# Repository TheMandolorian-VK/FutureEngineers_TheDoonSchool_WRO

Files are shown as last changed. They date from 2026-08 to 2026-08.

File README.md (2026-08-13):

<div align="center">

# The Doon School: WRO Future Engineers 2026

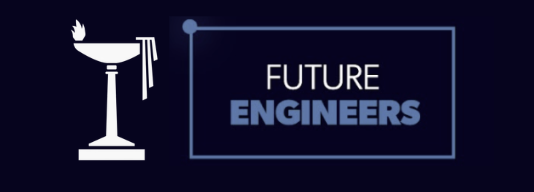
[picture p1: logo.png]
The Doon School: WRO Future Engineers 2026


### Engineering the autonomous vehicle for the World Robot Olympiad Future Engineers category

[Explore the project](#explore-the-project) · [System architecture](#system-architecture) · [Team](#team) · [Roadmap](#development-roadmap)

</div>

---

## Table of Contents

- [Overview](#overview)
- [Team](#team)
- [System Architecture](#system-architecture)
- [Mechanical Design](#mechanical-design)
- [Electronics and Power](#electronics-and-power)
- [Software and Obstacle Strategy](#software-and-obstacle-strategy)
- [Testing, Iteration and Evidence](#testing-iteration-and-evidence)
- [Visuals](#visuals)
- [Build and Upload](#build-and-upload)
- [Repository Use and Attribution](#repository-use-and-attribution)
- [Explore the Project](#explore-the-project)
- [Robot Visualisations](#robot-visualisations)
- [Documentation Standard](#documentation-standard)
- [Development Roadmap](#development-roadmap)
- [Repository History](#repository-history)
- [License](#license)

---

## Overview

This repository documents our work for **The Doon School Future Engineers** team competing at **WRO 2026 (GMR Arena, Hyderabad, 26–28 August 2026)**.

It captures the team's submitted vehicle configuration, software architecture, documentation structure, and engineering process. The vehicle is a 4-wheel autonomous car built to the WRO 2026 Future Engineers rules:

- **One driving axle + one steering actuator** per WRO rules.
- **Envelope:** ≤ 300 × 200 × 300 mm; **mass:** ≤ 1.5 kg.
- **No wireless** control during the run.

This documents our current vehicle design. Specifications, code, renders, and test results are in separate sections.

---

## Team

| Member | Focus |
| --- | --- |
| Dhrubo Mishra | Mechanical design |
| Vivaan Kumbhat | Software development |
| Yug Jain | Electronics, systems, and repository integration |
| Mr. Ashutosh Tripathi | Head mentor |

**School:** The Doon School, Dehradun, India
**Category:** WRO 2026: Future Engineers

---

## System Architecture

The vehicle separates **high-level perception and decision-making** (Raspberry Pi 4B) from **low-level actuator control** (ESP32). The Pi interprets the camera, decides steering/speed targets, and sends bounded commands over USB serial; the ESP32 drives the servo and motor and holds the safety state machine.

```text
Pi Camera Module 3 Wide
        │
Raspberry Pi 4B  ──(USB serial, 115200 baud)──►  ESP32
        │                                            │
   perception +                                   MG996R servo
     decision                                     (Ackermann)
                                                  TB6612FNG → N20 (rear axle)
```

| Layer | Input | Responsibility | Output | Module |
| --- | --- | --- | --- | --- |
| Perception | Camera frames | Detect colour cues / geometry | Feature observations | Pi camera + `wromain.py` |
| Decision | Observations + vehicle state | Route, avoid, recover, stop | Steering + speed targets | `wromain.py` |
| Control | Steering + speed targets | Constrain & actuate | Servo / PWM signals | `obstacleChallenge.ino` |
| Vehicle | Actuator signals | Steering + propulsion | Physical motion | Chassis + drivetrain |

> [!NOTE]
> This architecture is the submitted engineering reference. Test records and implementation evidence are kept separately from the configuration description.

### Vehicle specification (submitted configuration)

| Item | Specification |
| --- | --- |
| High-level compute | Raspberry Pi 4B |
| Low-level controller | ESP32 DevKit |
| Camera | Raspberry Pi Camera Module 3 **Wide** |
| Drive | **Rear-wheel drive**, 1 × N20 6 V 600 RPM on the rear axle |
| Steering | Front **MG996R** servo + **Ackermann linkage (LEGO beams/pins)**, 40° outer lock |
| Distance sensing | **VL53L0X** ToF (primary) + **HC-SR04** ultrasonic (redundant) |
| Orientation | **MPU6050** 6-axis IMU (DFRobot Fermion) |
| Motor driver | **TB6612FNG** (1 A/channel) |
| Chassis | 3 mm laser-cut plywood (LightBurn), brass standoff offsets, two decks |
| Battery | **11 V 3S LiPo** → motor/servo rail ~6 V (within N20 6 V and MG996R 4.8–7.2 V ratings); logic rail 5 V |
| Envelope / mass | ≤ 300 × 200 × 300 mm, ≤ 1.5 kg |

The rear N20 and its wheels are deliberately **smaller than the front wheels**, lowering the drive mass and giving the chassis a slight rearward tilt for corner stability.

---

## Mechanical Design

Full detail: [`design/README.md`](design/README.md).

Key points of the submitted configuration:

- **Front Ackermann steering** driven by an MG996R servo. The steering arms, knuckles and tie-rod geometry are built from **LEGO beams and pins** on a front sub-frame, so the Ackermann trapezoid can be re-jigged in 8 mm steps during tuning without re-cutting the chassis. Outer lock was iterated **31° → 40°** to clear the 600 mm corridor 90° corners (see journal Entry 04).
- **Fully rear-wheel drive** with one N20 6 V 600 RPM motor on the rear axle: Rule 11.13 compliant (one driving axle, no independent side motors). Rear wheels are smaller than the front, producing the rearward tilt described above.
- **Two-deck 3 mm plywood chassis**, laser-cut in **LightBurn**. Upper deck carries the Raspberry Pi 4B + Camera Module 3 Wide; lower deck carries the 11 V 3S LiPo pack, ESP32 and TB6612FNG. The decks are spaced by **brass standoff offsets**, with LEGO used as adjustable mounting rails.
- **Chassis:** 3 mm plywood, laser-cut in LightBurn. The DXF export [`wooden_plate.dxf`](design/wooden_plate.dxf) is committed (currently a placeholder rectangle; see [cut file notes](design/dxf_notes.md)). The full deck patterns and `.lbrn` LightBurn project are pending.
- **Mechanical BOM:** [`design/bom_mechanical.md`](design/bom_mechanical.md) lists every chassis and drivetrain part with status; the electronics parts list is in [`electronics/README.md`](electronics/README.md) (Bill of materials section).

---

## Electronics and Power

Full detail: [`electronics/README.md`](electronics/README.md) · Wiring: [`hardware/wiring-guide/README.md`](hardware/wiring-guide/README.md).

- **Two-rail power from one 11 V 3S LiPo pack:** the motor/servo rail is buck-regulated to ~6 V (within the N20 6 V and MG996R 4.8–7.2 V ratings) for the N20 + MG996R; the logic rail is buck-regulated to 5 V for the Pi 4B, ESP32, HC-SR04, VL53L0X and MPU6050.
- **Star grounding:** all logic grounds meet at one point; motor/servo currents return separately, keeping servo/motor noise out of the logic reference.
- **Protection:** both rails fused. The ESP32 enters `MODE_FAULT` (motor stop + centred steering) on serial timeout (>350 ms) or an invalid command; a logic-rail brownout resets the ESP32 into `MODE_STOP`, which is also motor-off and steering-centred.
- **Pin assignments** for the ESP32 (MG996R → GPIO 13; TB6612FNG PWMA/AIN1/AIN2/STBY → GPIO 25/26/27/32; status LEDs → GPIO 2/4) and the Pi↔ESP32 USB-serial link (115200 baud; messages `CMD,<steer>,<pwm>,<mode>` with `<mode>` ∈ {`DRIVE`, `PARK`, `FINISH`, `STOP`}, plus bare `STOP` and `PING`) are documented in the wiring guide.

> [!NOTE]
> The vehicle is in the development and integration phase; measured rail currents and calibrated values will be added to the testing records as subsystems are verified.

---

## Software and Obstacle Strategy

Full detail: [`strategy/README.md`](strategy/README.md) · Pi code: [`software/raspberry_pi/wromain.py`](software/raspberry_pi/wromain.py) · ESP32 code: [`software/esp32/obstacleChallenge.ino`](software/esp32/obstacleChallenge.ino).

Two-layer software:

- **Raspberry Pi (`wromain.py`):** camera frames → 3×3 colour grid → per-cell HSV masks (red, green, purple (the WRO magenta parking blocks), orange and blue; black is the neutral background cell) → contour detection → target selection → lateral-error **PD steering** → dynamic drive speed. PD (not full PID) is used deliberately: no sustained steady-state error needs the integral term, and D-only damping prevents corner oscillation.
- **ESP32 (`obstacleChallenge.ino`):** executes bounded commands through a safety state machine with internal states `MODE_DRIVE`, `MODE_PARK`, `MODE_STOP`, `MODE_FINISH`, `MODE_FAULT` (the Pi sends only the wire tokens `DRIVE`, `PARK`, `FINISH`, `STOP` and `PING`; invalid input drives `MODE_FAULT`). Fault is entered on serial timeout or invalid command: the vehicle always fails safe.

**Obstacle Challenge flow (implemented in code: vision grid + PD steering + watchdog; remaining stages are designed and tracked as planned work):** lane-follow by centring on the corridor (PD on vision offset; wall check is pending the VL53L0X integration) → red pillar pass right / green pillar pass left (colour from the camera grid, +12° bias; ToF clearance check pending) → after 3 laps the Pi sends `PARK`. **Planned but not yet in code:** the start-zone lap detector, the parking manoeuvre, and the IMU heading alignment / ToF depth stop for the magenta (purple) parking blocks. **Open Challenge:** corner handling via the PD controller today; wall-geometry corner detection and orange/blue section-line lap counting are planned.

Edge cases handled in code: lost line (re-acquire by sweep), serial dropout (watchdog fault stop), pillar too close (emergency bias). Planned: parking overshoot recovery with small IMU-controlled steps once the IMU is integrated.

> [!NOTE]
> Build status: the vehicle is in the development and integration phase. Code implements perception (colour grid), PD steering, dynamic speed, and the ESP32 safety state machine; the IMU, VL53L0X ToF, start-zone detector and parking manoeuvre are pending integration (placeholder interfaces in `wromain.py`). Measured results land in [`docs/testing/`](docs/testing/README.md) and [`evidence/`](evidence/README.md) as tests are run.

---

## Testing, Iteration and Evidence

Full detail: [`docs/testing/README.md`](docs/testing/README.md) · Journal: [`docs/engineering_journal/README.md`](docs/engineering_journal/README.md) · Evidence: [`evidence/README.md`](evidence/README.md).

Configuration is kept separate from evidence. A design choice is explained in the architecture/strategy material; an observed conclusion is recorded in the corresponding test record. Each test record lists date, objective, vehicle/software version, setup, procedure, raw observations, result, limitations and next action. Unsuccessful tests are retained as part of the real iteration process.

| Evidence type | Location | Required label |
| --- | --- | --- |
| Design decision | [Engineering journal](docs/engineering_journal/README.md) | Date, author, options, rationale |
| Proposed diagram | [Diagrams / wiring guide](hardware/wiring-guide/README.md) | Proposed + version |
| Physical / software test | [Testing](docs/testing/README.md) | Date, setup, method, observation |
| Test visual | [Test images](images/testing/README.md) | Date and conditions |
| Vehicle view | [Robot images](images/robot/README.md) | Render or dated photograph |
| Run video | [Videos](videos/README.md) | Date, challenge, setup, outcome |

---

## Visuals

The repository keeps team, vehicle, testing and competition visuals in separate folders so context stays clear. Vehicle views in [`images/robot/`](images/robot/README.md) are concept renders of the submitted configuration: design-reference views, not photographs. Competition-day videos are recorded on the day of the event and archived in [`videos/README.md`](videos/README.md).

---

## Build and Upload

The submitted configuration documents the build-and-upload procedure: OS setup, library versions, camera configuration, Pi build command, ESP32 board/environment selection, required libraries (`ESP32Servo`, OpenCV), upload method, communication setup and a safe power-on sequence. Measured verification is maintained in the testing record rather than implied by the instructions.

- Pi: `software/raspberry_pi/wromain.py` (OpenCV + camera input).
- ESP32: `software/esp32/obstacleChallenge.ino` (uses `ESP32Servo`).

Exact dependencies and compile/upload commands belong in the respective software folders, linked to the journal records.

---

## Repository Use and Attribution

This repository contains our own work. We do not copy other teams' designs or code. Git history records our progress.

The documentation is organised against the five WRO 2026 Future Engineers criteria (Mobility & Mechanical Design, Power & Sensor Architecture, Software Architecture & Obstacle Strategy, Systems Thinking & Engineering Decisions, Reproducibility & GitHub Quality). The mapping from each criterion to the relevant files is maintained in [`docs/README.md`](docs/README.md).

---
## Explore the Project

| Area | Contents | Status |
| --- | --- | --- |
| [`design/`](design/) | Vehicle layout, mechanical decisions, LightBurn/DXF, mechanical BOM | Configuration |
| [`electronics/`](electronics/) | Components, power plan, wiring, pin assignments | System reference |
| [`strategy/`](strategy/) | Open / Obstacle Challenge logic and flow | Decision architecture |
| [`software/`](software/) | Raspberry Pi (`wromain.py`) and ESP32 (`obstacleChallenge.ino`) source | Control software |
| [`docs/`](docs/) | Engineering journal, diagrams, testing records | Engineering record |
| [`images/`](images/) | Team, robot (renders), testing, competition visuals | Visual reference |
| [`videos/`](videos/) | Dated run and presentation videos (competition day) | Run records |
| [`evidence/`](evidence/) | Dated reviews, calibration and test summaries | Evidence archive |

---

## Robot Visualisations

Visuals in [`images/robot/`](images/robot/) are concept renders of the submitted vehicle configuration: design-reference views, not photographs.

---

## Documentation Standard

We keep design docs, code, and test results separate.

- Each test record has date, setup, method, observations and next action.
- Renders are not photographs of the real vehicle.
- We keep unsuccessful attempts as part of the learning process.

---

## Development Roadmap

| Phase | Focus | Evidence added when complete |
| --- | --- | --- |
| `01` | Define architecture and component choices | Dated design decision |
| `02` | Assemble and document the first prototype | Labelled photographs and wiring record |
| `03` | Implement perception, control and communication | Source code and software test record |
| `04` | Test subsystems | Measured, dated test results |
| `05` | Integrate the vehicle | Complete challenge evidence |

---

## Repository History

This repository uses GitHub to track our engineering progress. Updates are committed as the team's work evolves.

---

## License

Published for educational use as part of WRO Future Engineers. Team materials may be updated during development.

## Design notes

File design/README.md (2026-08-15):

<div align="center">

# Vehicle Design

**Mechanical design of the WRO 2026 Future Engineers vehicle.**

[← Project home](../README.md) · [Electronics](../electronics/README.md) · [Engineering journal](../docs/engineering_journal/README.md)

</div>

---

## Documentation index

- [Rule compliance checklist](rules_checklist.md) - WRO 2026 requirements mapped to the design
- [Ackermann geometry](ackermann_geometry.md) - steering geometry, iterations and cornering analysis
- [Mass budget](mass_budget.md) - component mass estimates and margins
- [Assembly guide](assembly_guide.md) - step-by-step build sequence
- [Mechanical BOM](bom_mechanical.md) - chassis and drivetrain parts
- [Cut file notes](dxf_notes.md) - what wooden_plate.dxf contains today
- [Design decision log](design_decisions.md) - decisions and rejected alternatives
- [Laser cutter setup](laser_cutter_setup.md) - school laser workflow and kerf
- [Camera mount design](camera_mount.md) - camera placement and mount
- [Steering tuning plan](steering_tuning_plan.md) - on-mat steering verification

---

## 1. Design philosophy

Three constraints drive every mechanical choice:

1. **Rule compliance:** WRO 2026 requires a 4-wheel vehicle with **one driving axle and one steering actuator** (Rules 11.3, 11.5, 11.13). Differential drive and one-motor-per-side are disqualified.
2. **Envelope & mass:** ≤ 300×200×300 mm and ≤ 1.5 kg (Rules 11.1–11.2).
3. **Reproducibility:** everything must be rebuildable from files in this repository (LightBurn/DXF, STL, BOM).

The vehicle uses **front Ackermann steering with a servo** and **fully rear-wheel drive with one N20 motor**, on a **laser-cut 3 mm plywood double-stack chassis**. The rear N20 and its wheels are deliberately smaller than the front wheels, which lowers the drive/steering mass and gives the chassis a slight rearward (backward) tilt for stability through the 90° corners.

> [!NOTE]
> The design uses one driving axle (rear) and one steering actuator (front servo). Physical verification that both rear wheels receive torque is pending.

---

## 2. Design targets

The values below are **design targets** captured from the CAD layout and the current prototype. They are targets, not verified measurements: physical verification (envelope gauge, scale, and track/wheelbase callipers) is pending and will be logged in the engineering journal.

| Parameter | Target | Notes |
| --- | --- | --- |
| Envelope (L×W×H) | ≤ 300×200×300 mm | Hard rule limit (11.1–11.2); layout keeps margin |
| Wheelbase | ~150 mm | Distance between front and rear axle centres |
| Track (front / rear) | ~140 mm | Wheel centre spacing, kept equal for Ackermann |
| Deck spacing | ~35 mm | Vertical gap between upper and lower plywood decks |
| Ground clearance | ~12 mm | Chassis underside to mat; set by deck height and wheel size |
| Total mass | ≤ 1.5 kg | Target; see mass budget below |

### Mass budget

Component masses to be measured once the vehicle is assembled (see [mass budget](mass_budget.md)). The rule limit is 1.5 kg.

---

## 3. Steering: Ackermann geometry

**Why Ackermann:** at a corner, the inner front wheel must turn tighter than the outer front wheel, so all four wheels roll about a single instant centre. Without this (parallel steering), tyres scrub sideways, grip drops, and the car is unstable at speed: exactly what kills run consistency.

### Steering mechanism

- **Actuator:** TowerPro MG996R digital servo (high torque, metal gears).
- **Linkage:** servo horn → tie rod → steering knuckles (3D-printed), forming the Ackermann trapezoid. The steering arms, knuckles and tie-rod geometry are built from **LEGO beams and pins** on a front sub-frame, giving an adjustable, repeatable Ackermann trapezoid that can be re-jigged in 8 mm steps during tuning without re-cutting the chassis.
- **Geometry parameters (current):**
  - Maximum outer-wheel steer angle: **31°** (prototype 1)
  - Maximum outer-wheel steer angle: **40°** (prototype 2, current)
  - Inner/outer angle difference follows the Ackermann condition
    `cot(δ_o) − cot(δ_i) = track / wheelbase`.

### 31° → 40° iteration

| Parameter | Prototype 1 | Prototype 2 | Decision |
| --- | --- | --- | --- |
| Max steer angle | 31° | 40° | 40° selected |
| Turning radius (1000 mm corridor) | OK | Tighter | 40° |
| 600 mm corridor 90° corner clearance | clipped wall line (~0 mm) | ~80 mm each side | 40° |
| Servo transition harshness | Soft | Slightly harsher | Softened in PD control near lock |

The 40° lock lets the car execute the sharp 90° corners of the 600 mm corridor configuration while the PD controller softens gain near lock to avoid jerky transitions.

---

## 4. Chassis: laser-cut 3 mm plywood (LightBurn)

- **Material:** 3 mm plywood: lighter than acrylic at equal stiffness, damps motor vibration, doesn't crack at screw points, cuts cleanly and fast.
- **Tool:** school laser cutter, designed in **LightBurn**. The DXF export is committed as [`wooden_plate.dxf`](wooden_plate.dxf); see [cut file notes](dxf_notes.md)). The editable `.lbrn` LightBurn project and full deck patterns are pending.
- **Edge treatment:** two thin coats of clear varnish seal the cut edges against moisture and warp.

### Material tradeoff

| Material | Stiffness/weight | Cutting/fab | Durability | Verdict |
| --- | --- | --- | --- | --- |
| 3 mm plywood | Good stiffness per gram | Laser-cuts fast and clean | Damps vibration, resists screw cracking | **Selected** |
| Acrylic | Similar weight, more brittle | Laser-cuts well | Cracks at screw points under load | Rejected |
| 3D-printed (PLA/PETG) | Lower stiffness at low mass | Slow, layer-dependent | Flexible, warps near motors | Rejected for structure |
| Aluminium | Highest stiffness | Needs CNC/mill, not the school laser | Very durable, but heavier | Rejected (mass + tooling) |

The chassis prioritises low mass, fast iteration, and vibration damping on the school laser cutter. Plywood wins on all three against the alternatives above.

### LightBurn cut workflow (reproducibility)

The chassis is drawn in **LightBurn** and cut on the school laser cutter from 3 mm plywood. Reproducibility (Criterion 5) depends on the cut files carrying everything needed to re-cut the chassis identically:

- **Layers:** the lower deck carries the drivetrain/electronics cut-outs; the upper deck carries the Pi + camera-mount cut-outs and the brass-standoff holes.
- **Parameters recorded per file:** material (3 mm plywood), kerf compensation, and the cutter's power/speed setting for that material.
- **Files:** the DXF export [`wooden_plate.dxf`](wooden_plate.dxf) is committed. The editable `.lbrn` master and full deck patterns are pending.

### Double-stack layout: space utilisation

The 300×200 mm footprint is used vertically to fit the full system:

| Deck | Contents | Why |
| --- | --- | --- |
|  **Lower deck** | 11 V 3S LiPo pack, ESP32, TB6612FNG motor driver | Battery low for CG; short motor/servo wiring; servo + drive currents kept off the logic reference |
|  **Upper deck** | Raspberry Pi 4B, Camera Module 3 Wide | Camera horizon height ~120 mm; Pi clear of motor noise sources |

The two decks are separated and supported by **brass standoff offsets**, giving a rigid, ventilated sandwich that uses the height envelope efficiently.

### Wood + LEGO + brass offsets mounting system

Instead of drilling new holes for every iteration, we fuse three systems:

- **Wood (plywood decks):** primary structure, laser-cut precisely.
- **LEGO beams and pins:** universal mounting rails with a precise 8 mm hole grid: sensors, drivers and brackets can be moved in 8 mm steps without re-cutting the chassis. Quick, repeatable repositioning during testing.
- **Brass standoffs / offsets:** set deck spacing and create rigid mounting pillars; brass threads are far more durable than wood screws when parts are repeatedly removed.

This hybrid makes the mechanical design **iterative by construction**: a camera or sensor that needs a different position is moved in minutes, and the change is photographed for the engineering journal.

---

## 5. Why this layout satisfies the rules

- **One driving axle:** a single N20 motor on the rear axle. Both rear wheels driven through one mechanically coupled axle.
- **One steering actuator:** a single MG996R servo on the front Ackermann linkage.
- **No wireless:** all control and power on board.
- **Envelope and mass:** designed to stay within 300x200x300 mm and 1.5 kg (physical verification pending).

---

## 6. Drive: rear axle, single N20 motor

- **Motor:** N20 6 V 600 RPM micro metal gear motor (spare unit carried).
- **Transmission:** motor drives the rear axle through the gearbox.
- **Wheel:** front wheels ~40 mm diameter, high-traction rubber; **rear wheels are smaller (~30 mm design estimate)**, matched to the smaller rear N20. The rear bias lightens the drive end and produces the slight rearward chassis tilt described in §1; the axle is mechanically coupled (Rule 11.13 compliant: one driving axle, no independent side motors).

### Speed / torque reasoning

- **Top speed (driven wheel):** the driven rear wheels are the smaller ones (~30 mm design estimate), not the ~40 mm front wheels. Circumference ≈ π × 30 mm ≈ 94.2 mm. At the N20 free-run speed of 600 RPM (10 rev/s), the **theoretical no-load speed (design estimate)** is ≈ 94.2 mm × 10 ≈ 0.94 m/s. Real cruise speed is lower because of load, tyre slip, and the PD speed controller leaving margin for corners and parking. We plan to cruise near 0.55 m/s for consistency, well inside the 3-minute round.
- **Torque:** rolling resistance force for the vehicle mass is to be measured on the mat. The N20 stall torque is datasheet-typical and to be bench-confirmed. The design is expected to be speed-limited, not torque-limited: correct for a flat, low-friction mat.

---

## 7. Component placement

| Component | Location | Justification |
| --- | --- | --- |
|  Camera Module 3 Wide | Upper deck, forward | Sees pillars 0.5–1.5 m ahead; reaction distance at cruise speed |
|  VL53L0X ToF | Front centre | Pillar + parking-gap distance, mm-accurate, colour-independent |
|  HC-SR04 ultrasonic | Front corner | Redundant wall proximity (independent bus from I²C sensors) |
|  MPU6050 IMU | Centre of mass | Minimal lever-arm coupling into gyro; heading for turns/parking |
|  Raspberry Pi 4B | Upper deck | Vision processing, high-level decisions |
|  ESP32 | Lower deck | Real-time motor/servo control, safety state machine |
|  MG996R servo | Front axle, centre | Drives Ackermann linkage; shortest linkage run |
|  11 V 3S LiPo battery | Lower deck, rear | Low CG; counterbalances steering assembly; sole energy source for the motor/servo rail |

---

## 8. Current development status

The mechanical design is through its second iteration (31°→40° steering, double-stack chassis assembled). Integration and tuning are ongoing at the school lab; every change is logged in the [engineering journal](../docs/engineering_journal/README.md). The DXF export [`wooden_plate.dxf`](wooden_plate.dxf) is committed; the `.lbrn` master and full deck patterns are pending.

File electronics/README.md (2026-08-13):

<div align="center">

# Electronics

**Pin assignments and basic power-distribution reference for the WRO Future Engineers vehicle.**

[← Project home](../README.md) · [Hardware](../hardware/README.md) · [Wiring Guide](../hardware/wiring-guide/README.md) · [Diagrams](../docs/diagrams/README.md)

</div>

---

## Pinout

### ESP32

| Component | Function | ESP32 Pin |
| --- | --- | ---: |
| MG996R | Steering signal | GPIO 13 |
| TB6612FNG | PWMA | GPIO 25 |
| TB6612FNG | AIN1 | GPIO 26 |
| TB6612FNG | AIN2 | GPIO 27 |
| TB6612FNG | STBY | GPIO 32 |
| Green LED | Status | GPIO 2 |
| Red LED | Status | GPIO 4 |

The ESP32 controls the low-level actuators. The vehicle uses one N20 motor through the TB6612FNG.

### Raspberry Pi 4B

| Component | Connection / Interface | Purpose |
| --- | --- | --- |
| Pi Camera 3 Wide | Camera interface | Visual perception |
| ESP32 | USB | Control communication |
| 6-axis IMU | Sensor interface | Motion sensing |
| ToF sensor | Sensor interface | Distance sensing |

The exact IMU and ToF pin assignments will be added after the final physical modules and connections are confirmed.

---

> [!NOTE]
> This folder defines the submitted electronics and power configuration. Wiring evidence is tracked in the hardware area. The vehicle is in the development and integration phase; estimated / design target values will be confirmed and recorded as subsystems are verified during integration.

## 1. Bill of materials

| # | Part | Qty | Role | Status |
| --- | --- | --- | --- | --- |
| 1 | Raspberry Pi 4B | 1 | Vision, decision, high-level control | Owned |
| 2 | Raspberry Pi Camera Module 3 **Wide** | 1 | Colour + geometry perception (pillars, lines, blocks) | Owned |
| 3 | ESP32 (DevKit) | 1 | Real-time motor/servo control, safety state machine | Owned |
| 4 | Dual Motor Driver Module **TB6612FNG** (1 A) | 1 | Drive motor H-bridge (replaces L298N) | Owned |
| 5 | **N20 6 V 600 RPM** Micro Metal Gear Motor | 1 + spare | Rear-axle drive | Owned |
| 6 | **TowerPro MG996R** Digital High Torque Servo | 1 + spare | Ackermann steering | Owned |
| 7 | **DFRobot Fermion MPU6050** 6-Axis Breakout | 1 | IMU: yaw for corners, parking alignment | Owned |
| 8 | **VL53L0X** ToF Laser Distance Sensor | 1 | Front distance: pillars, parking gap | Owned |
| 9 | HC-SR04 ultrasonic | 1 | Redundant wall/obstacle proximity | Owned |
| 10 | 11 V 3S LiPo pack (single pack feeding both rails; motor/servo rail buck-regulated to ~6 V, logic rail buck-regulated to 5 V) | 1 | Two-rail power from one pack (WRO Appendix D guidance) | Owned |
| 11 | 5 V regulator / buck | 2 | Logic rail regulation | Owned |
| 12 | MG996R servo horn + Ackermann links (3D-printed) | 1 set | Steering linkage | Printed |
| 13 | 3 mm plywood decks (LightBurn-cut) + brass standoffs | 1 set | Chassis (see [design](../design/README.md)) | Cut |

**Design rationale for key parts** is documented in the [engineering journal](../docs/engineering_journal/README.md): entries 03 (motor), 04 (steering), 06 (TB6612FNG over L298N), 07 (power), 08 (sensors).

## 2. Power architecture (two-rail from one 11V 3S pack)

| Rail | Source | Consumers | Protection |
| --- | --- | --- | --- |
| Motor/servo rail | 11 V 3S LiPo pack → buck-regulated to ~6 V (within N20 6V and MG996R 4.8-7.2V ratings) | N20 motor, MG996R servo | 2 A fuse |
| Logic rail | 11 V pack → 5 V buck regulator | Pi 4B, ESP32, HC-SR04, VL53L0X, MPU6050 | 2 A fuse |

- **Star grounding:** all logic grounds meet at one point; motor ground returns separately to its pack negative. Motor/servo currents never flow through the logic reference.
- **Decoupling:** 0.1 µF ceramic on every IC VCC; 100 µF electrolytic on the 5 V rail.
- **Failure handling:** logic-rail brownout → ESP32 enters `MODE_FAULT` and stops the vehicle.
- The logic rail is produced by a **5 V buck regulator** from the 11 V pack (an earlier LM317 concept, R1 = 240 Ω / R2 = 720 Ω with 0.1 µF input / 10 µF output decoupling, was dropped because the 11 V input would make the linear regulator run hot). Final regulation, current capability, and thermal performance will be verified once the physical power system is assembled.

### Power budget (to be measured during integration)

Component currents to be measured with a multimeter on each rail once the physical power system is assembled.

| Load | Rail | Avg (measured) | Peak (measured) |
| --- | --- | --- | --- |
| Raspberry Pi 4B | Logic 5 V | TBD | TBD |
| ESP32 | Logic 5 V | TBD | TBD |
| Sensors (HC-SR04, VL53L0X, MPU6050) | Logic 5 V | TBD | TBD |
| MG996R servo | Motor/servo ~6 V | TBD | TBD |
| N20 motor | Motor/servo ~6 V | TBD | TBD |
| **Logic rail total** | 5 V | TBD | TBD |
| **Motor rail total** | ~6 V | TBD | TBD |

Measured values will be recorded here as each rail is tested.

### Two-rail, single-pack confirmation

Both rails are derived from the SAME single 11 V 3S LiPo pack. The pack feeds two independent buck regulators: one to the ~6 V motor/servo rail and one to the 5 V logic rail. This satisfies the WRO requirement of a single on-board power source while keeping high-current actuator loads electrically separated from sensitive logic, with star grounding and per-rail fuses.

### Sensor rationale

- **VL53L0X (primary distance):** laser time-of-flight giving millimetre-accurate, colour-independent ranging, so it is the main sensor for pillars, walls and parking gaps. Limitation: glass and very dark (black) surfaces can absorb or let the laser pass, returning unreliable readings, so we use a slight downward tilt and median filtering.
- **HC-SR04 (redundant distance):** ultrasonic proximity on an independent GPIO/trig-echo bus, used as a cross-check and fallback if the ToF reading is lost. It is less precise and affected by soft or angled surfaces, but its independence from the I2C bus adds fault tolerance.
- **MPU6050 (orientation):** 6-axis IMU providing heading and tilt for turning and parking alignment, used for yaw integration to confirm turn completion and parking squareness.

Exact module pin assignments (I2C addresses and GPIO/trig-echo wiring) will be finalised after the physical sensor modules are confirmed.

> [!WARNING]
> The 11 V 3S LiPo stores high energy. Balance-charge before every run, never exceed the N20 (6 V) and MG996R (4.8 to 7.2 V) rated voltages after regulation, and fit a fuse on each rail.

## 3. Interface plan (summary: full pin map in wiring guide)

| Interface | Path | Notes |
| --- | --- | --- |
| Vision | Pi ↔ Camera Module 3 Wide | CSI |
| Control link | Pi ↔ ESP32 | USB serial 115200, `CMD,<steer>,<pwm>,<mode>` with `<mode>` ∈ {`DRIVE`, `PARK`, `FINISH`, `STOP`} + bare `STOP`/`PING`; firmware internal states `MODE_DRIVE`…`MODE_FAULT` |
| Drive | ESP32 ↔ TB6612FNG ↔ N20 | PWM + direction |
| Steering | ESP32 ↔ MG996R | PWM servo |
| Distance | ESP32 ↔ VL53L0X (I²C), HC-SR04 (GPIO) | Median-filtered |
| Orientation | ESP32 ↔ MPU6050 (I²C) | Yaw integration |

## 4. Calibration plan

- Camera: exposure locked; HSV bounds auto-tuned at boot from first frames.
- MPU6050: zero-bias captured over 2 s at start.
- VL53L0X: 5-sample median filter; mounted at ~15° downward to avoid shallow-angle white-mat misreads.
- Servo: steering range re-verified after every reassembly (see design entry on 31°/40°).

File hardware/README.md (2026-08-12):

<div align="center">

# Hardware

**Physical vehicle integration, hardware configuration, and assembly reference.**

[← Project home](../README.md) · [Electronics](../electronics/README.md) · [Wiring Guide](wiring-guide/README.md) · [Design](../design/README.md)

</div>

---

The `hardware/` directory contains the physical hardware configuration and vehicle-integration information for the WRO Future Engineers robot.

The current intended system uses a Raspberry Pi 4B for high-level computation, an ESP32 for low-level actuator control, a Pi Camera 3 Wide for visual perception, a 6-axis MPU6050 IMU, a VL53L0X ToF sensor, an HC-SR04 ultrasonic sensor, an MG996R steering servo, a TB6612FNG motor driver, and one N20 6 V 600 RPM drive motor.

## Hardware Configuration

| Component | Function |
| --- | --- |
| Raspberry Pi 4B | High-level computation and navigation |
| Pi Camera 3 Wide | Visual perception |
| ESP32 | Low-level actuator control |
| MPU6050 | 6-axis motion sensing |
| VL53L0X | Time-of-flight distance sensing |
| HC-SR04 | Redundant proximity sensing |
| MG996R | Front Ackermann steering |
| TB6612FNG | Drive-motor controller |
| N20 6 V 600 RPM | Rear drivetrain |

The vehicle uses **one N20 motor** for the rear drivetrain.

## Physical Integration

The robot combines front Ackermann steering with a single rear drive motor. The mechanical structure uses 3 mm plywood, LightBurn-cut components, LEGO elements, and brass standoffs/offsets as documented in the design records.

Detailed mechanical decisions, fabrication files, dimensions, and design iterations are maintained in [`design/`](../design/).

## Wiring

The complete physical connection reference is maintained in [`wiring-guide/`](wiring-guide/).

This includes:

- ESP32 pin assignments;
- motor-driver connections;
- steering connections;
- power-distribution information;
- sensor interfaces;
- grounding;
- communication wiring.

## Electronics

The electrical component and power reference is maintained in [`electronics/`](../electronics/).

## Evidence

Physical photographs and measurements added to this directory should represent the actual vehicle and identify the relevant date/configuration.

Concept renders and planned configurations must not be presented as physical verification.

## Status

The hardware documentation represents the intended vehicle configuration and will be updated as the physical robot is assembled, wired, tested, and refined.

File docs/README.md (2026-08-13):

<div align="center">

# Documentation Hub

**The team's design record, engineering decisions, diagrams, and test evidence.**

[← Project home](../README.md) · [Design](../design/README.md) · [Strategy](../strategy/README.md)

</div>

---

> [!IMPORTANT]
> This directory separates **planned work** from **verified work**. A document is not evidence of a physical result unless it records a date, setup, method, and observed outcome.

| Section | Purpose | Current status |
| --- | --- | --- |
| [Diagrams](diagrams/README.md) | Architecture, wiring, and logic diagrams | 5 Mermaid diagrams committed; chassis/layout diagrams pending |
| [Engineering journal](engineering_journal/README.md) | Dated choices, iterations, and lessons (mapped to the WRO rubric) | Active |
| [Testing](testing/README.md) | Test plans and measured results | In progress |
| [Release notes](release_notes.md) | Repository-level milestones | Active |

## Documentation rule

Use one dated file per meaningful decision or test. Keep the source of each claim clear: **plan**, **calculation**, **simulation**, **observation**, or **measurement**.

## What the evaluators see (WRO 2026 rubric: max 30 points)

| Criterion | Max | Journal entries | Key files a judge should open |
| --- | --- | --- | --- |
| 1. Mobility and Mechanical Design | 6 | 01–05 | [engineering_journal](engineering_journal/README.md) entries 01–05, [design/](../design/README.md) (Ackermann geometry, assembly guide, rules checklist, mechanical BOM; `wooden_plate.dxf` is placeholder, `.lbrn` and full deck patterns pending) |
| 2. Power and Sensor Architecture | 6 | 06, 08, 11 | [engineering_journal](engineering_journal/README.md) entries 06/08/11, [electronics/](../electronics/README.md) (BOM + power architecture), [hardware/wiring-guide](../hardware/wiring-guide/README.md) |
| 3. Software Architecture and Obstacle Strategy | 6 | 08, 09, 10 | [strategy/](../strategy/README.md) (overview + [software_architecture.md](../strategy/software_architecture.md) deep-dive), [engineering_journal](engineering_journal/README.md) entries 08/09/10, [software/](../software/README.md) |
| 4. Systems Thinking and Engineering Decisions | 6 | 02–10 | [engineering_journal](engineering_journal/README.md) entries 02–10 (risk register in entry 10), [design/design_decisions.md](../design/design_decisions.md) |
| 5. Reproducibility and GitHub Quality | 6 | 01–11 + repo structure | Root [README.md](../README.md), [docs/README.md](README.md), [engineering_journal](engineering_journal/README.md) (all entries), [hardware/wiring-guide](../hardware/wiring-guide/README.md), [testing/procedures.md](testing/procedures.md), `design/wooden_plate.dxf` (placeholder); diagrams/STL/`.lbrn` pending |

## How this repository maps to the five documentation criteria

| Criterion | What judges look for | Key files to open first |
| --- | --- | --- |
| C1 Mobility & Mechanical Design | Torque/speed reasoning, tradeoffs, build evidence | docs/engineering_journal/README.md (entries 01-05), design/README.md, design/ackermann_geometry.md, design/assembly_guide.md |
| C2 Power & Sensor Architecture | Single-battery two-rail power, sensor choices, calibration | docs/engineering_journal/README.md (06, 08, 11), electronics/README.md, hardware/wiring-guide/README.md |
| C3 Software Architecture & Obstacle Strategy | State machine, PD steering, obstacle logic | strategy/README.md, strategy/software_architecture.md, docs/engineering_journal/README.md (08-10), software/ |
| C4 Systems Thinking & Engineering Decisions | "Chose X over Y because...", constraints, risks, iteration | docs/engineering_journal/README.md (02-10), design/design_decisions.md |
| C5 Reproducibility & GitHub Quality | Clear README, CAD, wiring, commits | README.md (root), docs/README.md, hardware/wiring-guide/README.md, docs/testing/procedures.md, design/wooden_plate.dxf (placeholder) |

> [!NOTE]
> STL models and the LightBurn `.lbrn` chassis source are not yet committed. The five Mermaid diagrams are committed. `design/wooden_plate.dxf` is a placeholder rectangle.

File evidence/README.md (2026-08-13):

<div align="center">

# Evidence Archive

**A dated trail of real progress, observations, and engineering review.**

[← Project home](../README.md) · [Testing records](../docs/testing/README.md) · [Photos](../images/README.md)

</div>

---

This folder holds dated evidence that does not belong with final media: design reviews, calibration records, test summaries, and change records.

For every record, state the date, what was observed, the configuration used, and the next action.

## Evidence log

Status legend: **Analysis** (conclusion from design calculation or bench observation, raw record to be attached), **Planned** (scheduled, not yet run), **Measured** (dated raw record archived).

| # | Date | Type | Summary | Status | Link |
| --- | --- | --- | --- | --- | --- |
| E1 | 2026-08-01 | Steering sweep | 31° vs 40° lock-angle comparison; 40° clears the 600 mm corridor with ~80 mm margin (design analysis from prototype notes; dated sweep log pending) | Analysis | journal 04, [steering geometry](../design/ackermann_geometry.md) |
| E2 | 2026-08-03 | Driver comparison | L298N dropout ~1.8 V vs TB6612FNG ~0.4 V at stall → driver changed | Analysis | journal 06 |
| E3 | 2026-08-05 | Power bench test | Brown-out observed on a single shared battery → power separation adopted (two-battery design, later superseded by the single-pack two-rail design) | Analysis | journal 07 (historical), journal 11 (current) |
| E4 | 2026-08-09 | Sensor bench | VL53L0X median filter expected to improve stability on a white mat at 15° mount (to be verified when the ToF is wired) | Planned | journal 08, testing T6 |
| E5 | 2026-08-11 | Software | ESP32 serial protocol + fail-safe (timeout → `MODE_FAULT`) | Planned | testing T5 |

> [!NOTE]
> The archive grows as the development cycle continues. Evidence is added when observed: simulated or predicted results are never recorded as physical-test evidence.

> [!IMPORTANT]
> No raw evidence files (photographs, data logs, or videos) are present in this archive yet. They will be archived here as the vehicle is built and tested, and only observed results will ever be recorded. Rows marked **Analysis** or **Planned** have no raw record attached yet.

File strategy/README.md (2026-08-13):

<div align="center">

# Challenge Strategy

**How the team plans to reason about the Open and Obstacle Challenges.**

[← Project home](../README.md) · [Software](../software/README.md) · [Diagrams](../docs/diagrams/README.md)

</div>

---

This folder holds the team's challenge plans, flow diagrams, pseudocode, assumptions, and design decisions. The strategy is implemented in `software/raspberry_pi/wromain.py` (decision layer) and `software/esp32/obstacleChallenge.ino` (execution layer).

> [!IMPORTANT]
> **Safety is built in.** The ESP32 enters `MODE_FAULT` on serial timeout (350 ms) or an invalid command, so a vision or link failure stops the vehicle instead of letting it run uncontrolled. The Pi sends only the wire tokens `DRIVE`, `PARK`, `FINISH`, `STOP`, or `PING`; the `MODE_*` names are internal firmware states and are never sent over the serial link.

## 1. System decision flow

```text
Camera frame
   │
   ▼
3×3 colour grid (red / green / purple / orange / blue / black)
   │
   ▼
Contour detection → target selection
   │
   ▼
Centering error → PD steering → dynamic drive speed
   │
   ▼
USB serial (115200) → ESP32
   │
   ▼
Wire: "CMD,<steer_deg>,<pwm>,<mode>"  (mode ∈ DRIVE, PARK, FINISH, STOP)
   │
   ▼
Firmware states: MODE_DRIVE / MODE_PARK / MODE_STOP / MODE_FINISH / MODE_FAULT
   │
   ▼
MG996R steering servo + TB6612FNG → N20 drive motor
```

**Why PD, not PID:** the field has no sustained steady-state error, so the integral term would only add windup and risk saturation. The derivative term damps oscillation at corners, which is the dominant stability concern during lane following. Logging the number of interventions per lap gives a measurable performance metric for tuning (see the [PID tuning log](../docs/other/pid_tuning_log.md)).

**Why dynamic drive speed:** a fixed speed either wastes time on straights or becomes unstable in corners and near walls. Drive PWM is lowered when the vision centring error is large, when a pillar is active, or when the distance estimate drops below the safety margin (currently the monocular estimate; the VL53L0X ToF interface is a placeholder until wired). This keeps the control loop stable without sacrificing lap time on open corridor sections.

## 2. Module map

`software/raspberry_pi/wromain.py` (decision layer, runs on the Pi):
- **Perception / grid:** captures the camera frame and builds a 3x3 colour grid of cells.
- **Colour masks:** OpenCV HSV masks for red, green, purple, orange, blue, black (black is the neutral/background cell). Note the WRO magenta parking blocks are labelled `purple` in the code (the `COLOR_CENTERS` key is `"purple"`), so strategy and code stay consistent.
- **Target selection:** picks the centring target (corridor centre, pillar side, or parking reference) from the grid and the current monocular distance estimate. The VL53L0X ToF interface in the code is still a placeholder (always returns no distance) and will supply the distance once the module is wired.
- **PD controller:** converts lateral error into a steering angle and a dynamic drive speed.
- **Serial interface:** sends `CMD,<steer_deg>,<pwm>,<mode>` (mode `DRIVE`, `PARK`, `FINISH` or `STOP`), sends bare `STOP`/`PING` and waits for the firmware `PONG`; never sends `MODE_*` tokens.

`software/esp32/obstacleChallenge.ino` (execution layer, runs on the ESP32):
- **Serial parser:** reads `CMD,<steer>,<pwm>,<mode>` and the bare commands `STOP`, `PING`. Unknown mode returns `ERR,BAD_MODE` and stays safe.
- **State machine:** `MODE_DRIVE`, `MODE_PARK`, `MODE_STOP`, `MODE_FINISH`, `MODE_FAULT`. On the wire the Pi sends the tokens `DRIVE`/`PARK`/`FINISH`/`STOP` inside `CMD,...` and the bare commands `STOP`/`PING`; invalid input drives `MODE_FAULT`.
- **Actuator drivers:** MG996R steering servo and TB6612FNG motor driver for the N20 motor.
- **Watchdog:** 350 ms serial timeout forces `MODE_FAULT` (motor stop + centring steer), so the car fails safe.

## 3. Open Challenge strategy (3 laps, randomised walls)

- **Lane keeping:** centre the vehicle on the corridor using the vision centring error; the wall-distance check that would use the VL53L0X is planned but not yet in code (ToF interface is a placeholder today).
- **Corners:** steer with the PD controller; the derivative term is clamped (±3.0) and drive speed drops with steering magnitude so transitions near the 40° lock stay calm. Wall-geometry corner detection is planned once the ToF is integrated.
- **Lap counting:** count crossings of section boundary markers (orange/blue lines): 8 sections per lap.
- **Finish:** after 3 laps, stop autonomously inside the finish section and hold position.

## 4. Obstacle Challenge strategy (3 laps + pillars + parking)

**Pillar rule (WRO 2026):** pass the **red** pillar on its **right**, the **green** pillar on its **left**. The pillars must not be moved.

1. **Detection:** camera grid detects pillar colour; distance comes from the current monocular estimate until the VL53L0X ToF is wired.
2. **Passing logic:** the centring target is biased toward the correct side of the pillar (red +12°, green -12°, reduced to 35% when the pillar is already on the required side); the ToF clearance re-check is planned once ToF is integrated. If the pillar is closer than the emergency margin, the car biases away immediately.
3. **Lap count** as in Open Challenge; pillars only have to be obeyed on the three official laps (per Appendix A, they may be bypassed either side afterwards). The lap counter is implemented but depends on a start-zone detector that is not yet wired.
4. **Parking (after 3 laps, planned; not yet in code):**
    - Detect the purple (the WRO magenta parking blocks) parking-limit blocks with the camera.
    - Align parallel to the outer wall using MPU6050 heading (IMU integration pending).
    - Enter the lot in small steps; VL53L0X measures the gap (ToF integration pending) and stops the car inside the 20 cm-wide lot, parallel within the 2 cm tolerance.
    - Overshoot handling: back up in small IMU-controlled steps, never touching the purple (the WRO magenta parking blocks) blocks (touching them ends the round with no parking points).

## 5. Edge cases and recovery

| Case | Behaviour |
| --- | --- |
| Line / colour lost | Slow sweep to re-acquire the grid; resume lane following once the corridor centre is found again |
| Serial dropout (Pi to ESP32) | Watchdog trips at 350 ms → `MODE_FAULT`: motor stop + centre steering (fails safe) |
| Invalid wire command | Firmware replies `ERR,BAD_MODE`, ignores the command, and stays in its current safe state |
| Pillar too close | Emergency bias away from pillar; ToF clearance re-check planned once ToF is integrated |
| Parking overshoot | Planned: small IMU-controlled reverse steps to bring the heading and position back inside tolerance (IMU integration pending) |
| Wall too close (600 mm corridor) | Planned: speed reduction + steer correction driven by the VL53L0X reading (ToF integration pending) |
| Surprise rule (Day 2) | Strategy parameters isolated as constants at the top of `wromain.py` so a new rule can be prepared without a code rewrite |

## 6. Wire protocol examples

The Pi sends the following on the USB serial link (115200 baud). These are the only valid wire tokens. The `MODE_*` names below are internal firmware states and are NOT sent.

| Pi sends | Meaning |
| --- | --- |
| `CMD,-15.50,140,DRIVE` | Steer -15.50 deg, PWM 140, drive mode |
| `CMD,0,0,FINISH` | Stop and mark round finished |
| `STOP` | Bare stop command (motor off, steer centred) |
| `PING` | Liveness check; firmware replies to confirm link |
| `CMD,0,90,PARK` | Steer centred, PWM 90, parking mode |

Any message with a mode other than `DRIVE`, `PARK`, `FINISH`, `STOP`, or a bare `PING`/`STOP` is rejected with `ERR,BAD_MODE` and the firmware remains safe.

## 7. Safety behaviour

- One power switch + one start button only (rules-compliant starting procedure).
- ESP32 fails safe on any communication loss or invalid command (watchdog 350 ms, or `MODE_FAULT` on bad input).
- The vehicle stops autonomously when the round end condition is met; no wireless communication is used at any point.

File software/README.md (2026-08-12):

<div align="center">

# Software

**Source code for the intended perception, decision, communication, and control system.**

[← Project home](../README.md) · [Strategy](../strategy/README.md) · [Testing](../docs/testing/README.md)

</div>

---

| Component | Intended responsibility | Location |
| --- | --- | --- |
| Raspberry Pi | High-level perception and decision logic | [raspberry_pi](raspberry_pi/README.md) |
| ESP32 | Low-level actuator control and communication | [esp32](esp32/README.md) |

## Change discipline

Record important behavioural changes in the engineering journal and link corresponding test evidence once it exists.

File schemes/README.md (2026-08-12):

<div align="center">

# Hardware

**Physical vehicle integration, wiring, and verified assembly information.**

[← Project home](../README.md) · [Electronics plan](../electronics/README.md) · [Design](../design/README.md)

</div>

---

> [!NOTE]
> This directory holds vehicle-integration records and wiring evidence aligned with the submitted configuration.

| Area | Purpose | Status |
| --- | --- | --- |
| [Wiring](wiring-guide/README.md) | Connection diagrams, power architecture, pin tables | Interface record |

## Evidence standard

Photographs and measurements added here must show the actual vehicle and state the date and configuration used.

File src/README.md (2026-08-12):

<div align="center">

# Software

**Source code for the intended perception, decision, communication, and control system.**

[← Project home](../README.md) · [Strategy](../strategy/README.md) · [Testing](../docs/testing/README.md)

</div>

---

> [!NOTE]
> Source files in this repository are under development. Their presence does not imply completed integration, safety validation, or successful physical runs.

| Component | Intended responsibility | Location |
| --- | --- | --- |
| Raspberry Pi | High-level perception and decision logic | [pi](pi/README.md) |
| ESP32 | Low-level actuator control and communication | [esp32/motor_control](esp32/motor_control/README.md) |

## Change discipline

Record important behavioural changes in the engineering journal and link corresponding test evidence once it exists.

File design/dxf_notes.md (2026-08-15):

# Cut File Notes: wooden_plate.dxf

The cut file [wooden_plate.dxf](wooden_plate.dxf) is the version-controlled 2D geometry for the laser-cut plywood decks. These notes document exactly what the file contains today, so nothing is implied that is not in the file.

## File facts

| Item | Value |
| --- | --- |
| Format | DXF, AC1021 (AutoCAD 2004) |
| Units | Millimetres (INSUNITS 4) |
| Geometry | One closed LWPOLYLINE rectangle |
| Rectangle corners | (216.5, 89.5) to (66.5, 209.5) |
| Rectangle size | 150 x 120 mm |
| Layers | Layer 0 / Layer_0, line type Continuous |

## What this means

The committed file currently carries a single rectangular test outline (150 x 120 mm). It is a placeholder for the cut geometry, not the full deck patterns. The full lower- and upper-deck patterns, cut layers, kerf compensation and power/speed settings live in the LightBurn project (`.lbrn`).

## Plan to make the file authoritative

1. Export the full lower- and upper-deck patterns from the LightBurn master into this DXF (or add the `.lbrn` to the repository alongside it).
2. Record the cutter power/speed settings and kerf compensation in the file notes so the decks re-cut identically.
3. Commit the updated file and reference the geometry from the [design overview](README.md).
4. Photograph the cut decks against the drawing for the [engineering journal](../docs/engineering_journal/README.md).

## Related documents

- [Design overview](README.md), chassis section
- [Laser cutter setup](laser_cutter_setup.md)
- [Assembly guide](assembly_guide.md)

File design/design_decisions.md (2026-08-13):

# Design Decision Log

A dated record of mechanical and system decisions, with the alternatives we rejected and why. Reversed decisions are kept with notes on what replaced them.

Status legend: **adopted** (current), **superseded** (a later decision replaced it), **pending** (not yet executed).

| Date | Decision | Options considered | Chosen | Reason | Status |
| --- | --- | --- | --- | --- | --- |
| 12-08-26 | Chassis material | Plywood, acrylic, 3D-printed PLA/PETG, aluminium | 3 mm plywood | Lightest per stiffness on the school laser, damps motor vibration, does not crack at screw points | Adopted |
| 12-08-26 | Steering geometry | Parallel vs Ackermann | Ackermann | Inner wheel turns tighter, no tyre scrub, stable through 90° corners | Adopted |
| 12-08-26 | Steering actuator | One MG996R vs two motors | One MG996R | One steering actuator is the rule; servo torque suits the LEGO linkage | Adopted |
| 12-08-26 | Drive layout | Two motors (one per side) vs one N20 rear axle | One N20 rear axle | Simpler, fewer parts, single axle drives both wheels | Adopted |
| 12-08-26 | Rear wheel size | Equal wheels vs smaller rear wheels | ~30 mm rear, ~40 mm front | Rear bias lightens the drive end and gives a rearward tilt for cornering stability | Adopted |
| 12-08-26 | Mounting system | Dedicated drilled holes vs LEGO grid + brass standoffs | LEGO 8 mm grid + standoffs | Iterative by construction: move sensors/brackets in 8 mm steps without re-cutting the chassis | Adopted |
| 13-08-26 | Deck stack | Single deck vs double stack | Double stack | Uses the height envelope; battery low for CG, Pi/camera up for horizon | Adopted |
| 13-08-26 | Power architecture | Two batteries vs one 11 V 3S two-rail | One 11 V 3S two-rail | Single source, two rails (~6 V motor/servo, 5 V logic); see [electronics](../electronics/README.md) | Adopted (supersedes the earlier two-battery idea) |
| 13-08-26 | Steer angle | 31° vs 40° | 40° | Reaches the 600 mm corridor corners; PD softens the servo near lock | Adopted |
| 13-08-26 | Cadence | N/A | 31° then 40° | Prototype 1 at 31° was too wide for the sharp corners; prototype 2 set to 40° | Superseded by 40° |

## Notes

- Reversals are logged: the two-battery idea (13-08-26) was replaced by the single-pack two-rail design on the same day.
- New decisions are appended here with the current date, never edited into an older row, so the log stays chronological.

## Related documents

- [Design overview](README.md)
- [Engineering journal](../docs/engineering_journal/README.md)
- [Release notes](../docs/release_notes.md)

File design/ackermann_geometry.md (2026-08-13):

# Ackermann Steering Geometry

The vehicle uses front Ackermann steering with a single MG996R servo. This document records the geometry parameters, the prototype iterations, and the cornering analysis behind the current 40 degree setting.

## Why Ackermann

In a corner the inner front wheel travels on a tighter arc than the outer front wheel. Ackermann geometry angles the two front wheels differently (inner steers further than outer) so that all four wheels roll about a single instant centre. With parallel steering the tyres scrub sideways, grip drops, and the vehicle is unstable at speed. Ackermann is what keeps the run consistent through the competition's 90 degree corners.

## Geometry parameters

| Parameter | Value | Notes |
| --- | --- | --- |
| Wheelbase | ~150 mm | Front to rear axle centres (design target) |
| Track | ~140 mm | Wheel centre spacing, kept equal front and rear (design target) |
| Steer angle, outer wheel (current) | 40° | Prototype 2 |
| Steer angle, outer wheel (prototype 1) | 31° | Superseded |
| Linkage | Servo horn to tie rod to knuckles | Knuckles 3D-printed; geometry jigged on a LEGO 8 mm grid |

## The Ackermann condition

For a given turn, the inner and outer steer angles relate through:

```
cot(outer) - cot(inner) = track / wheelbase
```

With track ~140 mm and wheelbase ~150 mm the required angle difference is small but necessary. The knuckle steering-arm angles and tie-rod length are set in the CAD/LightBurn layout to match this condition, then verified mechanically by measuring the inner and outer angles at full lock.

## Prototype iterations

| Parameter | Prototype 1 | Prototype 2 | Decision |
| --- | --- | --- | --- |
| Max outer steer angle | 31° | 40° | 40° selected |
| Turning radius (design estimate) | ~250 mm | ~180 mm | 40° |
| 600 mm corridor 90° corner clearance | Clipped wall line (~0 mm) | ~80 mm each side | 40° |
| Servo transition harshness | Soft | Slightly harsher | PD softened near lock |

## Turning radius

For small slip the turning radius follows R = wheelbase / tan(outer steer angle).

- At 31°: 150 mm / tan(31°) ≈ 250 mm (design estimate)
- At 40°: 150 mm / tan(40°) ≈ 180 mm (design estimate)

The 40 degree lock reaches the 600 mm corridor corners with margin. The PD controller softens servo gain near lock.

## Verification plan

1. Measure inner and outer steer angle at full lock with a protractor against the wheel face.
2. Measure actual turning radius on the mat (left and right, should be symmetric).
3. Confirm no tyre scrubbing at full lock in a slow straight roll.
4. Log results in the [tuning log](../docs/other/pid_tuning_log.md) and the [engineering journal](../docs/engineering_journal/README.md).

## Related documents

- [Design overview](README.md), steering section
- [Steering tuning plan](steering_tuning_plan.md)
- [Mechanical BOM](bom_mechanical.md)

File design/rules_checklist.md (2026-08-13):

# WRO 2026 Rule Compliance Checklist

Vehicle rule compliance for the WRO Future Engineers 2026 season. This checklist maps every mechanical requirement to the design decision that satisfies it and to the evidence that confirms it.

Status legend:

- **Designed:** satisfied by the current design intent, not yet physically verified.
- **To verify:** check needed at the build or on the day.
- **Verified:** confirmed on the physical vehicle and logged in the [engineering journal](../docs/engineering_journal/README.md).

## Vehicle construction rules

| Rule | Requirement | Design answer | Status |
| --- | --- | --- | --- |
| 11.1-11.2 | Envelope ≤ 300x200x300 mm | Double-stack plywood layout keeps the 300x200 mm footprint; deck spacing ~35 mm keeps height low | To verify with the envelope gauge at the build |
| 11.1-11.2 | Mass ≤ 1.5 kg | [Mass budget](mass_budget.md) framework ready; to be measured with a scale | To verify with a scale |
| 11.3 / 11.5 | Exactly **one driving axle** | Single N20 6 V motor drives the rear axle; both rear wheels driven through one mechanically coupled axle | To verify both rear wheels receive torque |
| 11.3 / 11.5 | No differential drive, no one-motor-per-side | No independent side motors planned | To verify |
| 11.13 | Exactly **one steering actuator** | Single MG996R servo on front Ackermann linkage | To verify |
| - | Four wheels in contact | Two front (steered) + two rear (driven) wheels | To verify |
| - | No wireless control | All control and power on board | To verify |

## Competition behaviour rules

| Rule | Requirement | Design answer | Status |
| --- | --- | --- | --- |
| - | Complete the obstacle course autonomously | On-board vision (Pi 4B + Camera Module 3 Wide) + ToF/ultrasonic/IMU + ESP32 state machine | To verify in test runs |
| - | Park correctly after the course | Camera + ToF parking-gap detection, dynamic speed control, PD softening near lock | To verify in test runs |

## Notes

- The steering and drive definitions follow the interpretation used across the [design overview](README.md) and [engineering journal](../docs/engineering_journal/README.md).
- Any rule clarification from the national or international organisers that affects the design is recorded in the [engineering journal](../docs/engineering_journal/README.md) as a new entry.
- Rule numbers refer to the WRO 2026 Future Engineers rules; confirm against the latest published version before the event.

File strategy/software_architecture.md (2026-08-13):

# Software Architecture

Deep-dive into the two-layer software system, grounded in the actual source code. This document is the reference for Criterion 3 (Software Architecture and Obstacle Strategy).

## System split

| Layer | Runs on | Responsibility | Module |
| --- | --- | --- | --- |
| Perception + decision | Raspberry Pi 4B | Camera capture, HSV colour grid, contour detection, target selection, PD steering, dynamic speed, serial commands | `software/raspberry_pi/wromain.py` |
| Execution + safety | ESP32 DevKit | Servo control, motor PWM, communication watchdog, emergency stop, status LEDs | `software/esp32/obstacleChallenge.ino` |

The Pi sends bounded actuator commands at 25 Hz over USB serial (115200 baud); the ESP32 executes them or enters `MODE_FAULT` if the link drops.

## Control loop (Pi)

The main loop in `wromain.py` runs once per camera frame:

```
Capture frame (1280x720 @ 60 fps)
   |
Update IMU / ToF (placeholders today)
   |
Gaussian blur -> HSV conversion
   |
3x3 grid: split frame into 9 cells (top/middle/bottom x left/center/right)
   |
Per-cell: create colour masks for expected colours (GRID_COLORS)
   |
Per-cell: contour extraction -> detections list
   |
Detect pillars (red/green, area >= PILLAR_MIN_AREA)
   |
Detect track lines (orange/blue, bottom 45% of frame)
   |
Target selection:
   - Pillar detected? -> use pillar centring error + bias
   - Line detected?  -> use lane centring error
   - Nothing?        -> SEARCH mode, reset PD
   |
PD steering: error -> steering_deg (clamped +/-45)
   |
Speed: BASE_SPEED - steering_fraction*80 - pillar - close_distance
   |
Send: "CMD,<steer>,<pwm>,<mode>" to ESP32
   |
Debug drawing (grid, detections, panel)
```

### Command rate

`ESP32_COMMAND_HZ = 25.0` (40 ms period). The Pi sends one `CMD` per frame (or faster if the frame rate is lower). The ESP32 watchdog timeout is 350 ms, so up to ~8 commands can be missed before a fault.

## Vision pipeline

### 3x3 colour grid

The frame is divided into 9 cells:

| Row | Height ratio | Vertical range |
| --- | --- | --- |
| Top | 40% | 0 to 40% |
| Middle | 20% | 40% to 60% |
| Bottom | 40% | 60% to 100% |

| Column | Width ratio | Horizontal range |
| --- | --- | --- |
| Left | 30% | 0 to 30% |
| Center | 40% | 30% to 70% |
| Right | 30% | 70% to 100% |

Each cell checks only its expected colours (defined in `GRID_COLORS`):

| Cell | Expected colours |
| --- | --- |
| top_left, top_center, top_right | red, green |
| middle_left, middle_center, middle_right | red, green, purple |
| bottom_left, bottom_center, bottom_right | orange, blue |

Black is checked in all cells except middle_center and bottom_center (per `BLACK_GRID`).

### HSV colour detection

Each colour is defined by a centre point in OpenCV HSV space and a tolerance (adjustable via a live trackbar):

| Colour | H | S | V | HSV range note |
| --- | --- | --- | --- | --- |
| red | 0 | 210 | 180 | wraps around 0/179 |
| green | 60 | 190 | 150 | |
| blue | 110 | 200 | 160 | |
| purple | 145 | 180 | 150 | WRO magenta parking blocks |
| orange | 15 | 220 | 180 | |

The `create_color_mask` function builds an inRange mask from the centre +/- tolerance, with hue tolerance = 35% of tolerance, and min saturation/value = centre - 2*tolerance.

### Contour extraction

`detect_objects` finds external contours on each mask, filters by area >= `MIN_AREA` (100 px), and computes the centroid (cx, cy) and bounding box (x, y, w, h) for each detection.

## Target selection

Priority order (highest wins):

1. **Pillars:** if red or green detections exist with area >= `PILLAR_MIN_AREA` (250 px), select the higher-scored pillar. Score = 0.6 * area + 0.4 * cy (larger and lower in the frame wins). The pillar's centring error becomes the steering input.
2. **Track lines:** if left and/or right orange/blue lines are detected in the bottom 45% of the frame, compute lane centre and error. Left/right split at frame midpoint.
3. **Search:** if nothing is detected, reset the PD controller and steer straight (SEARCH mode).

## PD controller

```python
error = lateral offset normalized to [-1, 1]
if abs(error) <= CENTER_DEADZONE (0.05): error = 0

derivative = (error - prev_error) / dt
derivative = clamp(derivative, -MAX_DERIVATIVE, +MAX_DERIVATIVE)  # 3.0

output = KP * error + KD * derivative  # KP=32, KD=10
output = clamp(output, -45, +45)  # degrees
```

The derivative clamp prevents spike-induced jerks. The deadzone (5% of frame width) avoids small corrections at centre.

## Pillar bias

When a pillar is active, `apply_pillar_strategy` adds a fixed bias to the steering output:

- Red pillar: +12 degrees (pass right)
- Green pillar: -12 degrees (pass left)

If the pillar is already on the required side of the frame centre, the bias is reduced to 35% (36% of 12 = ~4.2 degrees).

## Speed control

```python
steering_fraction = abs(steering_deg) / 45
speed = 165 - 80 * steering_fraction  # base 165, reduction 80 at full lock
if pillar_active: speed -= 15
if distance < 30 cm: speed -= 25  # monocular estimate today
speed = clamp(speed, 75, 210)  # PWM value
```

## ESP32 firmware

### State machine

```
MODE_STOP (initial)
   |
   v
MODE_DRIVE <-- CMD,...,DRIVE
MODE_PARK  <-- CMD,...,PARK
MODE_FINISH <-- CMD,...,FINISH
   |
   v (timeout or bad command)
MODE_FAULT (motor off, centred steering, red LED on)
```

### Serial protocol

| Command | Format | Response |
| --- | --- | --- |
| Drive/park | `CMD,<steer>,<pwm>,<mode>` | `ACK,CMD` |
| Stop | `STOP` | `ACK,STOP` |
| Ping | `PING` | `PONG` |
| Bad prefix | any | `ERR,BAD_PREFIX` |
| Bad steering | non-numeric | `ERR,BAD_STEERING` |
| Bad motor PWM | out of range | `ERR,BAD_MOTOR` |
| Bad mode | not DRIVE/PARK/FINISH/STOP | `ERR,BAD_MODE` |
| Buffer overflow | >128 chars | `ERR,BUFFER_OVERFLOW` |
| Unknown | anything else | `ERR,UNKNOWN_COMMAND` |

### Watchdog

`COMMAND_TIMEOUT_MS = 350`. If no valid command arrives within 350 ms, the ESP32 enters `MODE_FAULT`: motor stopped, steering centred, red LED on, green LED off.

### Status LEDs

| State | Green LED (GPIO 2) | Red LED (GPIO 4) |
| --- | --- | --- |
| Healthy (command recent, no fault) | ON | OFF |
| Fault or timeout | OFF | ON |

### Debug output

Every 1000 ms, the ESP32 prints a status line on serial:

```
STATUS,mode=DRIVE,steering=0.0,motor=150,command_age_ms=42
```

## Honest gaps (not yet implemented)

The following are placeholder interfaces in `wromain.py` and do not affect behaviour:

| Placeholder | Code location | What it does today |
| --- | --- | --- |
| IMU (MPU6050) | `IMUInterface` class | `available = False`; `gyro_z_dps = 0.0` |
| ToF (VL53L0X) | `ToFInterface` class | `available = False`; `distance_cm = None` |
| Start-zone detector | `start_zone_detected` variable | Always `False` (lap count never increments) |
| Parking manoeuvre | Main loop: `if lap_count >= TARGET_LAPS: mode = "PARK"` | Sets mode but no parking logic; the vehicle just keeps driving |
| Monocular distance | `estimate_distance` function | Active (KNOWN_OBJECT_HEIGHT_CM=20, FOCAL_LENGTH_PX=700); returns an approximate cm value used for speed reduction |

Until these are wired and implemented, the vehicle runs on vision + PD only. The code is structured so each placeholder can be filled in without changing the rest of the system.

## Related documents

- [Strategy overview](README.md)
- [Testing procedures](../docs/testing/procedures.md)
- [Engineering journal entry 09](../docs/engineering_journal/README.md)

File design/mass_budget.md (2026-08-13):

# Mass Budget

Component masses to be measured once the vehicle is assembled. The rule limit is 1.5 kg (Rules 11.1-11.2).

## Budget (to be filled in with a scale)

| Component | Measured mass (g) | Notes |
| --- | --- | --- |
| Two plywood decks + brass standoffs | TBD | 3 mm plywood, 4-6 standoffs |
| 11 V 3S LiPo battery | TBD | Sole energy source |
| N20 6 V motor + gearbox | TBD | Rear drive |
| MG996R servo | TBD | Steering |
| Raspberry Pi 4B | TBD | Vision and decisions |
| Camera Module 3 Wide | TBD | Upper deck, forward |
| ESP32 dev board | TBD | Real-time control |
| TB6612FNG driver + wiring | TBD | Motor/servo driver |
| Four wheels (front ~40 mm, rear ~30 mm) | TBD | Rear wheels smaller |
| LEGO rails and mounting hardware | TBD | 8 mm grid mounting |
| Misc (screws, tie rods, connectors) | TBD | Hardware allowance |
| **Total** | **TBD** | Must be under 1.5 kg |

## Procedure

1. Weigh each component individually on a digital scale.
2. Record the value in this table.
3. Sum the total and confirm it is under 1.5 kg.
4. Log the result in the [engineering journal](../docs/engineering_journal/README.md).

## Centre of gravity

The CG is intended to sit low and slightly rearward:

- The battery sits on the lower deck at the rear, and the N20 motor is at the rear axle. Together they pull the CG rearward.
- The steering assembly (servo, knuckles, tie rod) is lighter than the drive end, so the front stays light.
- Lower-deck mass keeps the CG low, which limits body roll through corners.

Once built, the CG is checked by balancing the vehicle on a thin fulcrum fore and aft of the axles and recorded in the [engineering journal](../docs/engineering_journal/README.md).

## Related documents

- [Design overview](README.md), design targets and mass section
- [Mechanical BOM](bom_mechanical.md)
- [Rule compliance checklist](rules_checklist.md)

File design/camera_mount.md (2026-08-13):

# Camera Mount Design

Mounting notes for the Camera Module 3 Wide on the upper deck. The mount exists to hold the camera at the design horizon height with the field of view covering the obstacles ahead.

## Placement

| Parameter | Design value | Notes |
| --- | --- | --- |
| Camera | Raspberry Pi Camera Module 3 Wide | Wide-angle lens |
| Deck | Upper deck, forward edge | Above the steering sub-frame, clear of the drive end |
| Horizon height | ~120 mm | From mat to lens centre, design target |
| Viewing distance | 0.5-1.5 m ahead | Reaction distance at the planned cruise speed (~0.55 m/s) |

## Why this placement

- The upper deck keeps the lens above the LEGO steering sub-frame and out of the front wheel arc at full lock.
- ~120 mm height balances a far view for cornering with a near view for parking-gap detection on the mat.
- The wide lens covers the 600 mm corridor walls side to side at the required look-ahead distance, so one camera is enough for wall following and pillar/parking detection.

## Mount construction

- The camera bracket is 3D-printed and fixed to the upper deck through a LEGO rail, so it can move fore and aft in 8 mm steps during tuning.
- The bracket STL is pending in the repository; until it is committed the mount is jigged with LEGO and the position is photographed into [images/robot/](../images/robot/README.md).
- A soft mounting pad between the bracket and deck damps motor vibration reaching the sensor.

## Checks after mounting

| Check | How |
| --- | --- |
| Lens height | Ruler from mat to lens centre |
| Tilt level | Bubble level on the bracket face |
| View ahead clear | Camera preview at max steer, both directions |
| Firmness | No visible shake in the preview when the motor runs |

Results of these checks are logged in the [engineering journal](../docs/engineering_journal/README.md).

## Related documents

- [Design overview](README.md), component placement
- [Assembly guide](assembly_guide.md)
- [Strategy](../strategy/README.md), sensing section

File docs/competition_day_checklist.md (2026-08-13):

# Competition Day Checklist

Team must complete before WRO 2026 (Aug 26-28). Items marked "Required" must be done to reach 25+ documentation score.

## Physical Evidence (Required)

- [ ] Real robot photos (minimum 5 angles: front, rear, left, right, top)
- [ ] Test run video - Open Challenge (3 laps)
- [ ] Test run video - Obstacle Challenge (3 laps + parking)
- [ ] Measured mass on digital scale
- [ ] Measured current draw per rail (multimeter)
- [ ] Actual turning radius (measured on mat)
- [ ] Wheel diameter (calipers)
- [ ] Steering angle at full lock (protractor)

## Code Integration (Required)

- [ ] IMU wired and `available=True` in code
- [ ] VL53L0X ToF wired and returning real distance
- [ ] Start-zone detector working
- [ ] Parking manoeuvre functional
- [ ] All placeholder interfaces replaced with real code

## Documentation (Required)

- [ ] `.lbrn` LightBurn master committed
- [ ] Full DXF deck patterns committed (replacing placeholder)
- [ ] Steering knuckle STL files committed
- [ ] Camera mount STL committed
- [ ] Real robot photos in `images/robot/`
- [ ] Test videos in `videos/`
- [ ] Test results logged in `docs/testing/README.md`
- [ ] Mass budget filled in `design/mass_budget.md`
- [ ] Power budget filled in `electronics/README.md`

## Competition Day

- [ ] Robot fits in 300x200x300mm envelope gauge
- [ ] Robot weighs under 1.5kg on official scale
- [ ] Both rear wheels receive torque (lifted test)
- [ ] Steering symmetric left/right
- [ ] No wireless communication active
- [ ] Battery fully charged
- [ ] Spare parts packed (spare N20, spare MG996R)
- [ ] USB cable for last-minute code upload

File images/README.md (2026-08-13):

<div align="center">

# Visual Documentation

**Visual material for the team, vehicle, testing, and competition progress.**

[← Project home](../README.md) · [Evidence policy](../README.md#documentation-standard)

</div>

---

| Collection | Purpose | Status |
| --- | --- | --- |
| [Robot](robot/README.md) | Concept renders; physical vehicle views later | Partial (3 concept renders present) |
| [Team](team/README.md) | Team photograph and identification material | In preparation (no media yet) |
| [Testing](testing/README.md) | Dated photos and screenshots from real tests | Reserved (no media yet) |
| [Competition](competition/README.md) | Dated practice or event documentation | Reserved for competition-day (no media yet) |

> [!CAUTION]
> Concept renders must always remain labelled as renders. They are not photographs or proof of physical construction.

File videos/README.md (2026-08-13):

<div align="center">

# Videos

**Run videos, demonstrations, and project presentations.**

[← Project home](../README.md) · [Test visuals](../images/testing/README.md)

</div>

---

Link to or store videos of actual vehicle runs here. Every entry should state the date, challenge, setup, and whether the run completed.

> [!NOTE]
> Videos are for **competition day ONLY**. No recordings have been made yet: our vehicle is still in the development stage, so a run video has not been prepared at this point. This situation has been discussed with the WRO India Team directly via phone conversations and emails, and they have been kept informed of our timeline.

| Future collection | Intended content | Status |
| --- | --- | --- |
| [obstacle_challenge](obstacle_challenge/README.md) | Complete obstacle-course attempts | Reserved (no media yet) |
| [open_challenge](open_challenge/README.md) | Complete open-course attempts | Reserved (no media yet) |
| [project_presentation](project_presentation/README.md) | Team project explanation | Reserved (no media yet) |

> [!CAUTION]
> Do not label planned, simulated, or edited concept material as a physical vehicle run.

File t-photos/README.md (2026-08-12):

<div align="center">

# Team

**The people behind The Doon School Future Engineers project.**

[← Project home](../README.md) · [Vehicle photos](../v-photos/README.md)

</div>

---

Add a team photograph here only if every pictured person has agreed to its use in this public repository. Use a descriptive filename, for example `team-2026-08-12.jpg`.

> [!NOTE]
> This folder is currently reserved for a future team photograph.

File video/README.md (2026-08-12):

<div align="center">

# Videos

**Run videos, demonstrations, and project presentations.**

[← Project home](../README.md) · [Test visuals](../v-photos/testing/README.md) · [Video manifest](video.md)

</div>

---

Link to or store videos of actual vehicle runs here. Every entry should state the date, challenge, setup, and whether the run completed.

| Future collection | Intended content |
| --- | --- |
| [obstacle_challenge](obstacle_challenge/README.md) | Complete obstacle-course attempts |
| [open_challenge](open_challenge/README.md) | Complete open-course attempts |
| [project_presentation](project_presentation/README.md) | Team project explanation |

> [!CAUTION]
> Do not label planned, simulated, or edited concept material as a physical vehicle run.

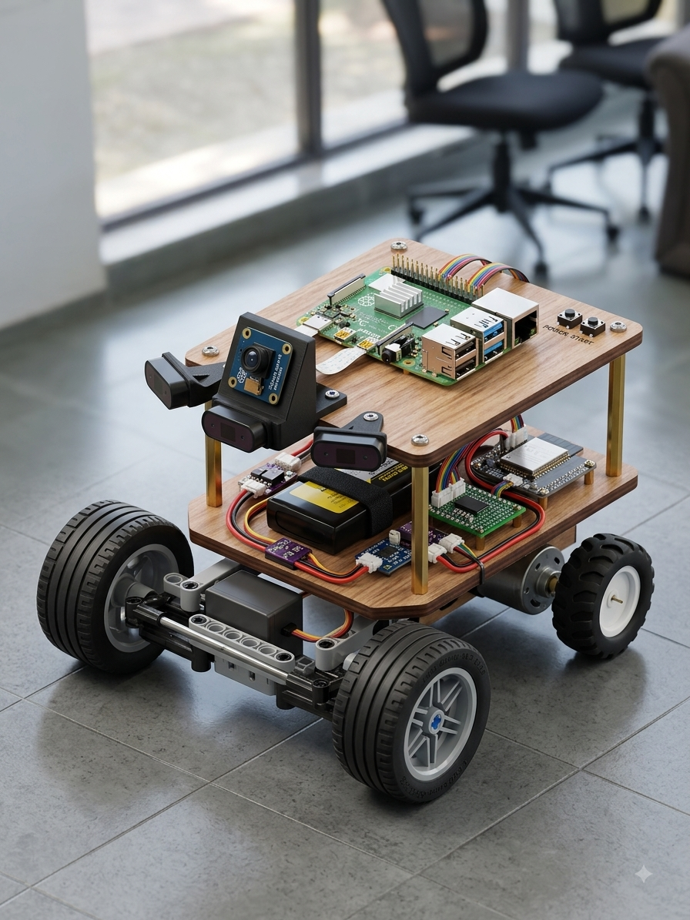
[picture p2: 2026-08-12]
images/robot/render_3.png

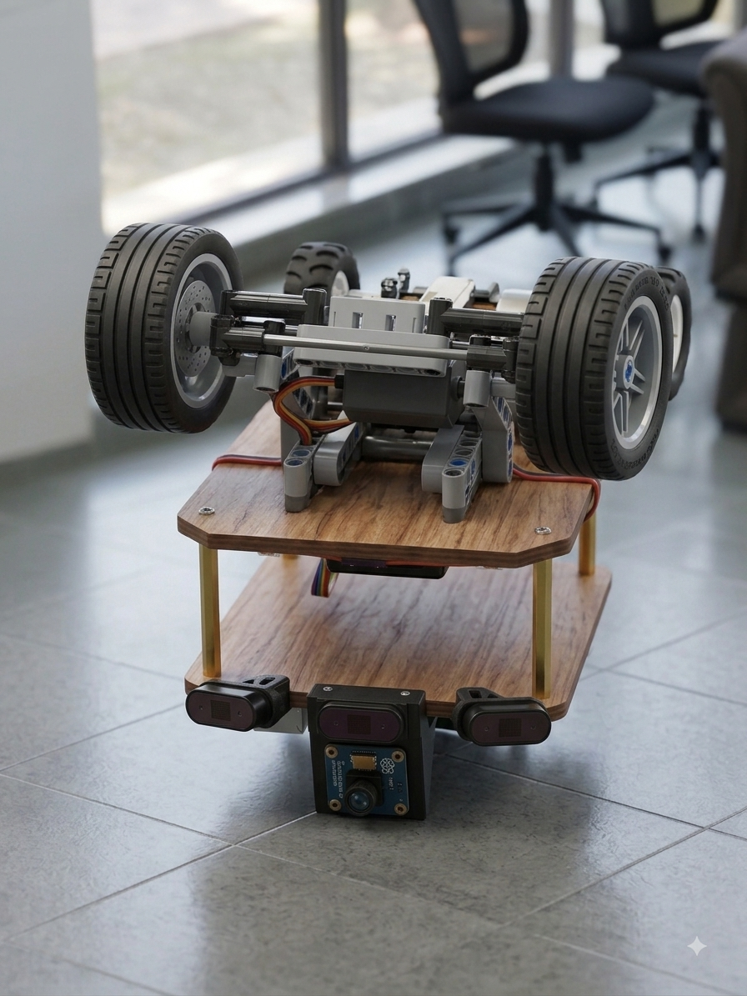
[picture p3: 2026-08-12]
images/robot/render_1.png

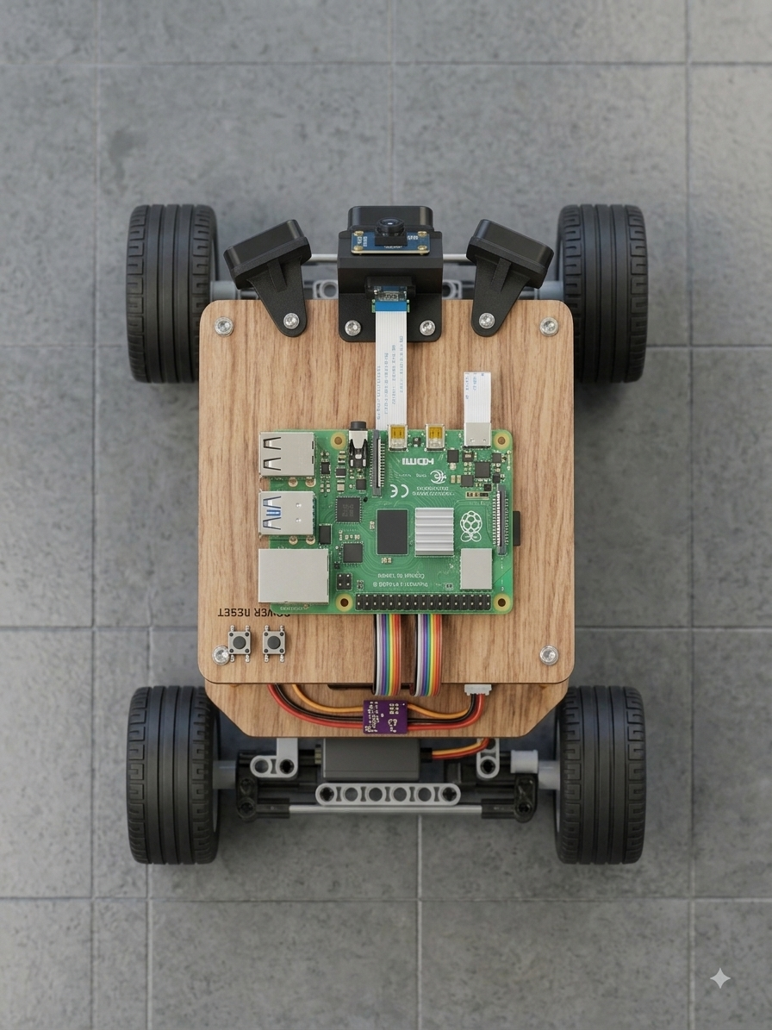
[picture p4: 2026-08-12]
images/robot/render_2.png

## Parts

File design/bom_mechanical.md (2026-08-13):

# Mechanical Bill of Materials

Parts list for the chassis and drivetrain. This excludes the electronics (see the [electronics guide](../electronics/README.md)). Quantities and statuses are reviewed each build; statuses marked "to confirm" are checked before the next cut.

Status legend: **in hand** (already owned), **to confirm** (quantity or spec to be confirmed), **pending** (to be sourced or modelled).

| Part | Qty | Spec | Status |
| --- | --- | --- | --- |
| Plywood deck sheet | 1 | 3 mm, laser-cuts cleanly | In hand |
| Brass standoffs | 4-6 | M3, ~35 mm effective spacing | In hand |
| N20 gear motor | 1 (+1 spare) | 6 V, ~600 RPM, spare carried | In hand |
| Rear wheels | 2 | ~30 mm diameter, driven axle | To confirm |
| Front wheels | 2 | ~40 mm diameter, high-traction rubber | To confirm |
| TowerPro MG996R servo | 1 (+1 spare) | Metal gear, 4.8-7.2 V | In hand |
| Steering knuckles | 2 | 3D-printed, STL pending in repo | Pending |
| Tie rod | 1 | Connects horn to knuckles | To confirm |
| LEGO beams and pins | Assorted | 8 mm grid mounting rails | In hand |
| LEGO axle and connectors | Assorted | Steering and mounting | In hand |
| Servo horn | 1 | Included with servo | In hand |
| Screws, nuts, washers | Assorted | M2/M3 | In hand |
| Cable ties and adhesive pads | Assorted | Cable management and mounting | In hand |
| Clear varnish | 1 | Two coats on cut edges | In hand |

## Notes

- The spare N20 and spare MG996R are field-repair parts carried to the event, not fitted.
- The steering knuckle STL files are the only mechanical part still to be committed to the repository; until then the geometry is defined by the LEGO sub-frame jig in the [design overview](README.md).
- Update this file when a status changes so the repository stays the single source of truth for a rebuild.

## Related documents

- [Design overview](README.md)
- [Assembly guide](assembly_guide.md)
- [Mass budget](mass_budget.md)

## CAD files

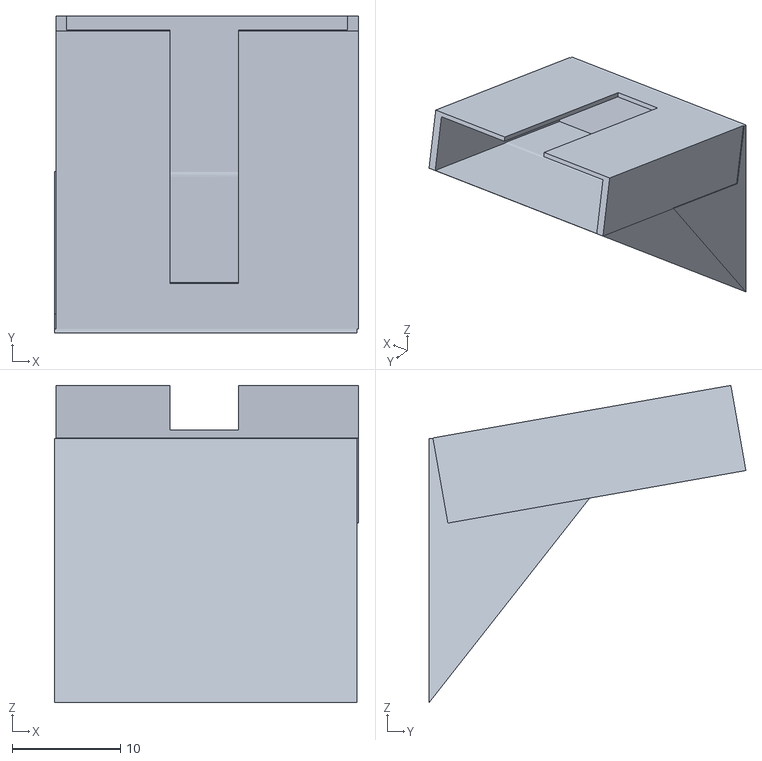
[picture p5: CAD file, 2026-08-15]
design/piCamBracket_v1.3.stl
28.1 x 29.3 x 29.4

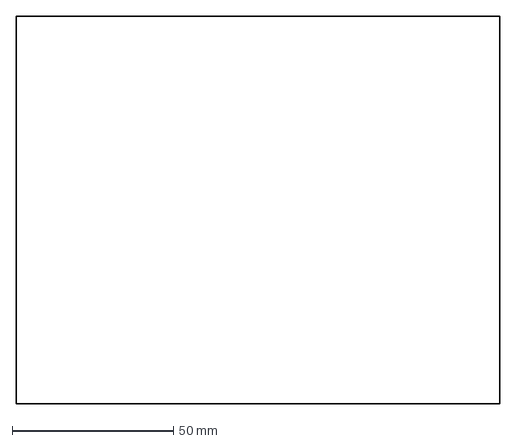
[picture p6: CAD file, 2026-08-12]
design/wooden_plate.dxf
150.0 x 120.0 mm

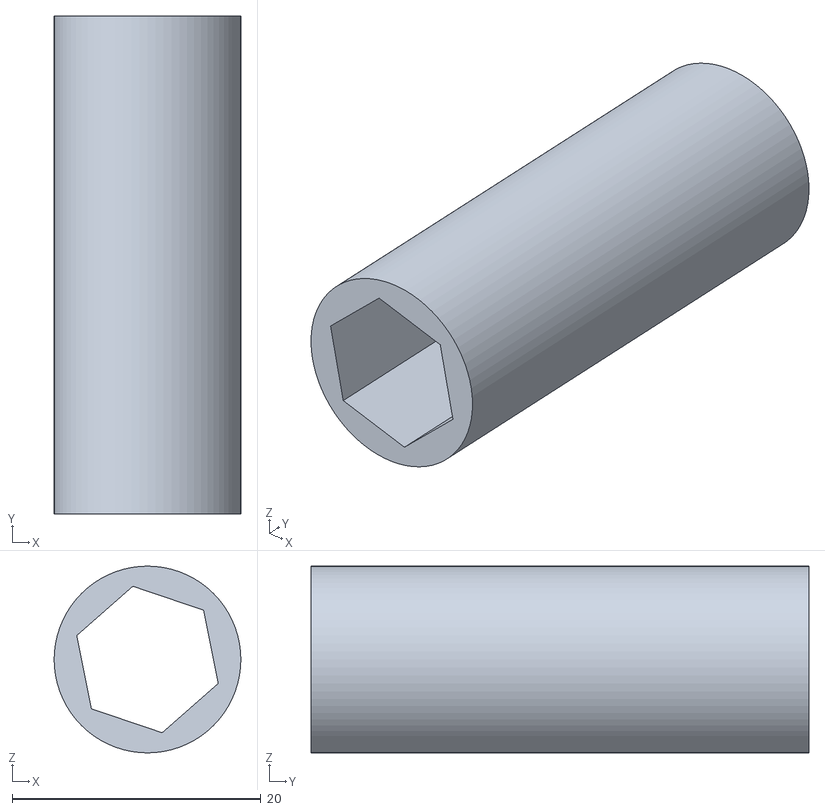
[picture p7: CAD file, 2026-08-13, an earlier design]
design/legacy_offset.stl
15.0 x 40.0 x 15.0

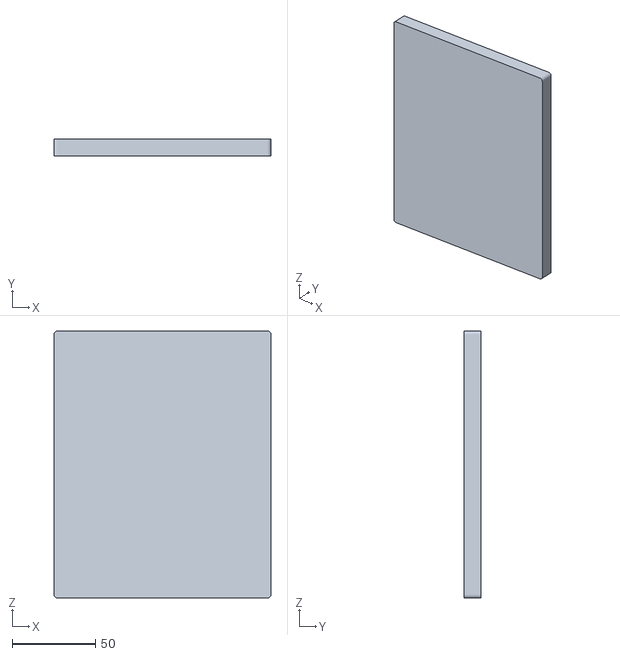
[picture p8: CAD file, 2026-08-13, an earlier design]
design/legacy_chassis.stl
130.0 x 10.0 x 160.0

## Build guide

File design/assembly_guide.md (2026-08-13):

# Chassis Assembly Guide

Step-by-step build sequence for the laser-cut plywood chassis. A future team rebuilds the vehicle by following this guide with the cut file and the [mechanical BOM](bom_mechanical.md).

Read the [design overview](README.md) first. Follow the [electronics guide](../electronics/README.md) for the wiring that is referenced below.

## Tools and consumables

- School laser cutter (see [laser cutter setup](laser_cutter_setup.md))
- 3 mm plywood, clear varnish, small brush
- Screwdriver set (M2/M3), pliers, small ruler, marker
- Brass standoffs (M3, ~35 mm effective deck spacing)
- LEGO beams, pins, axle and connector assortment
- Adhesive pads or double-sided tape for the electronics

## Steps

### 1. Cut the decks

Cut the two plywood decks from [wooden_plate.dxf](wooden_plate.dxf) geometry, following the [laser cutter setup](laser_cutter_setup.md) power/speed settings. The lower deck carries the drivetrain and electronics cut-outs; the upper deck carries the Pi and camera-mount cut-outs and the standoff holes.

### 2. Seal the edges

Apply two thin coats of clear varnish to the cut edges. This stops moisture warp and splintering during handling and rework.

### 3. Lower deck: drivetrain

- Fit the rear axle and both rear wheels (~30 mm) onto the lower deck, aligned to the axle cut-outs.
- Mount the N20 6 V motor so its gearbox drives the rear axle directly.
- Mount the ESP32, TB6612FNG driver and battery tray per the [electronics layout](../electronics/README.md). Battery sits rear for CG.
- Check both rear wheels rotate freely and that nothing binds on the deck.

### 4. Steering sub-frame (front)

- Build the front sub-frame from LEGO beams on the front of the lower deck. The 8 mm grid lets the geometry be re-jigged without re-cutting.
- Fit the MG996R servo on the centre line of the front axle.
- Connect the servo horn to the tie rod and the tie rod to both 3D-printed steering knuckles to form the Ackermann trapezoid (see [Ackermann geometry](ackermann_geometry.md)).
- Set full-lock steer angles to the current setting (40°) and check inner/outer symmetry.

### 5. Standoffs and upper deck

- Fix the brass standoffs to the lower deck at the marked holes.
- Lower the upper deck onto the standoffs and secure it. Deck spacing ends up ~35 mm.
- Mount the Raspberry Pi 4B and the camera on the upper deck, forward, at the design horizon height (~120 mm). See [camera mount](camera_mount.md).

### 6. Wire the vehicle

- Route power and signal wires from the lower-deck electronics to the upper-deck Pi and to the servo and motor, following the [electronics wiring guide](../electronics/README.md).
- Keep servo and drive currents off the logic reference, and keep the power leads short.

### 7. Photograph and log

- Photograph each finished stage into [images/robot/](../images/robot/README.md).
- Log deviations from this guide in the [engineering journal](../docs/engineering_journal/README.md).

## Checks after assembly

| Check | How | Record to |
| --- | --- | --- |
| Envelope ≤ 300x200x300 mm | Envelope gauge | Engineering journal |
| Mass ≤ 1.5 kg | Scale | [Mass budget](mass_budget.md) |
| Both rear wheels driven | Lifted slow run | Engineering journal |
| Steering symmetric | Protractor on wheel faces | [Tuning log](../docs/other/pid_tuning_log.md) |
| No binding at full lock | Slow roll full left and right | Engineering journal |

## Related documents

- [Mechanical BOM](bom_mechanical.md)
- [Laser cutter setup](laser_cutter_setup.md)
- [Rule compliance checklist](rules_checklist.md)

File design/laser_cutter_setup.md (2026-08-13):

# Laser Cutter Setup

Procedure for cutting the plywood decks on the school laser cutter. The specific power/speed values are recorded in the LightBurn master and are copied here when confirmed.

## Material

- 3 mm plywood, flat and dry, sheet slightly larger than the part.
- Check for knots or voids in the cut area before loading; they change the cut quality.

## Machine prep

1. Open the cutting file in LightBurn (the DXF geometry, or the `.lbrn` master when it is in the repo).
2. Confirm the file units are millimetres.
3. Set the origin to the lower-left of the sheet.
4. Run a focus and a small test cut on a scrap corner before the real cut.
5. Set the power/speed for 3 mm plywood (values recorded in the `.lbrn`); if not yet confirmed, do a kerf test first.

## Kerf

- Cut a short slot in scrap, measure the slot width, and set the kerf compensation in LightBurn so the parts come out at the drawn size.
- The kerf value is noted in the `.lbrn` and should be written here once measured on the school machine.

## Cutting

- Cut the lower deck and upper deck separately.
- Monitor the cut; plywood can flare if the speed is too low or the focus drifts.
- Let the parts cool before handling; the edges are hot.

## After the cut

1. Check the parts against the drawing dimensions with a ruler or callipers.
2. Fit check: parts should slide together without forcing and without play at the standoff holes.
3. Apply two thin coats of clear varnish to the cut edges (see [assembly guide](assembly_guide.md)).
4. Photograph the decks and the cutting setup into [images/testing/](../images/testing/README.md).
5. Note the measured kerf and power/speed in the [engineering journal](../docs/engineering_journal/README.md).

## Safety

- Keep the machine supervised for the whole cut.
- Keep the exhaust running; do not open the lid until the job ends.
- No flammable materials near the bed while cutting.

## Related documents

- [Cut file notes](dxf_notes.md)
- [Assembly guide](assembly_guide.md)
- [Design overview](README.md), chassis section

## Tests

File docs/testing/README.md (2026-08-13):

<div align="center">

# Testing Records

**Plans, procedures, observations, and measured results.**

[← Documentation](../README.md) · [Evidence archive](../../evidence/README.md) · [Tuning log](../other/pid_tuning_log.md)

</div>

---

Add a dated Markdown record for every physical or software test. State the objective, setup, hardware/software version, procedure, raw measurements or observations, outcome, and next action.

Detailed methodology for each test (T1-T10) is in [`procedures.md`](procedures.md).

**Suggested filename:** `YYYY-MM-DD-short-test-name.md`

## Test plan summary

| # | Date | Test | Status | Result link |
| --- | --- | --- | --- | --- |
| T1 | 2026-08-01 | Servo sweep + steering range (31° vs 40°) |  In progress | [geometry + analysis](../../design/ackermann_geometry.md) |
| T2 | 2026-08-03 | Motor driver comparison: L298N vs TB6612FNG dropout |  In progress | journal entry 06 |
| T3 | 2026-08-06 | PD steering tuning on straight + corner |  In progress | [`../other/pid_tuning_log.md`](../other/pid_tuning_log.md) |
| T4 | 2026-08-08 | Camera HSV detection under two lighting setups |  In progress | N/A |
| T5 | 2026-08-10 | Serial protocol fail-safe (timeout → MODE_FAULT) |  Planned | N/A |
| T6 | 2026-08-12 | Wall-follow with VL53L0X in 600 mm corridor |  Planned | N/A |
| T7 | 2026-08-14 | Pillar pass logic (red right / green left) |  Planned | N/A |
| T8 | 2026-08-16 | Parallel parking sequence (camera + IMU + ToF) |  Planned | N/A |
| T9 | 2026-08-18 | Full Open Challenge: 3 laps + finish stop |  Planned | N/A |
| T10 | 2026-08-20 | Full Obstacle Challenge: 3 laps + pillars + parking |  Planned | N/A |

## Standard test procedure

1. Record date, software version (git hash), battery state, lighting.
2. Define pass/fail metric before running.
3. Run ≥5 repetitions; log all outcomes (pass/fail/partial).
4. Keep failing runs: they document the iteration cycle.
5. Link every result to a photo or video in [`images/testing/`](../../images/testing/README.md) or [`videos/`](../../videos/README.md).

## Test-record template

Use one dated file per test (suggested name `YYYY-MM-DD-short-test-name.md`). Copy this skeleton and fill only what was actually observed:

```markdown
# Test: <name> (<YYYY-MM-DD>)

- Objective:
- Setup (hardware/software version, git hash, battery state, lighting):
- Procedure:
- Raw measurements / observations:
- Outcome (pass / fail / partial):
- Linked evidence (photo/video/file):
- Next action:
```

> [!IMPORTANT]
> Until a test is actually run, use a test plan and label it **Planned**. Do not add predicted values as results.

> [!NOTE]
> The vehicle is in the development and integration phase; results are added as tests are completed at the Doon School lab. Test evidence is recorded when measured, never assumed.

> [!NOTE]
> Raw measurement records, photos, and videos will be added to this folder and the `evidence/` archive as the vehicle is built and run. Nothing here is fabricated: tests marked **Planned** or **In progress** have no raw data yet.

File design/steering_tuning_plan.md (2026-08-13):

# Steering Tuning Plan

How the steering is tuned and verified once the vehicle is on the mat. This plan is to be executed at the school lab; results are logged in the [tuning log](../docs/other/pid_tuning_log.md) and the [engineering journal](../docs/engineering_journal/README.md). Nothing here is a claim of results.

## Goals

- Confirm the 40 degree full-lock steer angle reaches the 600 mm corridor corners with ~80 mm clearance each side.
- Confirm the PD controller softens the servo near lock so the transition is not jerky.
- Confirm left and right steering symmetry.

## Pre-run mechanical checks

| Check | Pass criteria |
| --- | --- |
| Toe angle | Wheels straight and parallel at centre |
| Inner/outer angle at lock | Ackermann condition holds within protractor accuracy |
| Steering slop | No free play in the tie rod joints |
| Full-lock binding | Slow roll at full lock, both sides, no binding |

## Run sequence

1. **Straight-line hold:** run straight, measure lateral drift over 2 m. Adjust centre trim.
2. **Constant-radius circle:** fixed steering command, record circle diameter left and right. Symmetry check.
3. **600 mm corridor 90° corner:** approach at cruise speed, record wall clearance left and right, adjust PD gain near lock.
4. **S-curve:** two corners back to back to check the servo transitions.
5. **Parking approach:** slow speed, camera + ToF, record final gap error.

## Parameters that may be tuned

| Parameter | Where | Logged to |
| --- | --- | --- |
| Centre trim offset | Steering | Tuning log |
| PD proportional gain | Steering | Tuning log |
| PD derivative gain | Steering | Tuning log |
| Softening near lock | Steering | Tuning log |
| Cruise speed | Drive | Tuning log |

## Definition of done

The 600 mm corridor run is completed repeatedly without touching the walls, and the parking approach ends inside the gap tolerance, at which point the results are recorded and the design is locked for the event.

## Related documents

- [Ackermann geometry](ackermann_geometry.md)
- [Tuning log](../docs/other/pid_tuning_log.md)
- [Testing overview](../docs/testing/README.md)

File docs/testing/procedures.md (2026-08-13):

# Test Procedures

Detailed methodology for each planned test (T1-T10). Every procedure defines the objective, setup, steps, pass criteria, and data to record. Tests are run at the Doon School lab; results land in the corresponding dated test file in this folder.

## T1: Servo sweep + steering range

- **Objective:** confirm the MG996R produces symmetric 40° outer lock and that the Ackermann inner/outer angle difference matches the design.
- **Setup:** vehicle on the bench (wheels off the ground), servo powered, Pi connected via USB serial.
- **Steps:**
  1. Send `CMD,-40,0,DRIVE` and photograph the steering linkage; measure outer-wheel angle with a protractor.
  2. Send `CMD,40,0,DRIVE` and repeat for the other side.
  3. At full lock, measure the inner-wheel angle and compute the Ackermann difference.
  4. Repeat 5 times and log all angles.
- **Pass criteria:** both sides reach 40° ± 2°; inner angle > outer angle (Ackermann condition met); symmetry within 3°.
- **Data to record:** protractor photos, measured angles, pass/fail per side, any binding or jitter.

## T2: Motor driver comparison

- **Objective:** measure voltage dropout of L298N vs TB6612FNG under the N20 motor load.
- **Setup:** bench power supply at 6 V, N20 motor, both drivers tested sequentially, multimeter across motor terminals.
- **Steps:**
  1. Wire the N20 to the L298N; run at full PWM; measure the voltage across the motor at stall and at free-run.
  2. Repeat with the TB6612FNG.
  3. Record dropout = supply voltage minus measured motor voltage.
- **Pass criteria:** TB6612FNG dropout < 0.5 V; L298N dropout > 1 V (confirming the design choice).
- **Data to record:** supply voltage, motor voltage at stall and free-run, dropout for each driver.

## T3: PD steering tuning

- **Objective:** tune KP and KD to minimise lateral oscillation on a straight and through a 90° corner.
- **Setup:** vehicle on the mat, camera on, corridor walls in place, serial log running.
- **Steps:**
  1. Start with KP=32, KD=10 (current values). Drive straight for 2 m. Log lateral offset and intervention count.
  2. Adjust KP in increments of 4; repeat. Find the KP that centres the vehicle with minimal oscillation.
  3. With optimal KP, adjust KD in increments of 2; repeat through a 90° corner. Find the KD that damps overshoot without adding jitter.
  4. Log all runs in the [PID tuning log](../other/pid_tuning_log.md).
- **Pass criteria:** straight-line drift < 50 mm over 2 m; corner entry/exit without wall contact.
- **Data to record:** KP/KD values, lateral offset, intervention count, pass/fail per run.

## T4: Camera HSV detection

- **Objective:** verify the camera detects red, green, purple (magenta), orange, and blue objects under fluorescent and spot lighting.
- **Setup:** each colour block placed at 0.5 m, 1.0 m, 1.5 m from the camera; two lighting conditions (fluorescent overhead, desk spot lamp).
- **Steps:**
  1. Place each colour block in turn; capture a frame; adjust the tolerance trackbar until detection is stable.
  2. Log the tolerance value and detection status (detected / not detected / intermittent) for each colour at each distance.
  3. Switch lighting and repeat.
- **Pass criteria:** all five colours detected at all three distances under both lighting conditions, with tolerance in the range 20-60.
- **Data to record:** colour, distance, lighting, tolerance, detection status, photos of the debug window.

## T5: Serial fail-safe

- **Objective:** confirm the ESP32 enters `MODE_FAULT` (motor stop + centred steering) within 350 ms of the last valid command.
- **Setup:** ESP32 powered, serial connected, motor and servo wired, green/red LEDs visible.
- **Steps:**
  1. Send `CMD,0,150,DRIVE` to start the motor running.
  2. Stop sending commands. Time the delay from the last command to the motor stopping (use a stopwatch or serial timestamp).
  3. Repeat 5 times.
- **Pass criteria:** motor stops and steering centres within 350 ms ± 50 ms on all 5 runs; red LED illuminates.
- **Data to record:** measured timeout per run, LED state, pass/fail.

## T6: VL53L0X wall-follow

- **Objective:** verify the VL53L0X provides stable distance readings in the 600 mm corridor and that the vehicle can maintain a consistent wall distance.
- **Setup:** 600 mm corridor walls, VL53L0X wired and mounted at ~15° downward, serial log running.
- **Steps:**
  1. Place the vehicle at the corridor entrance. Log the raw VL53L0X readings for 10 s while stationary.
  2. Drive through the corridor at 0.3 m/s. Log distance readings vs time.
  3. Compute mean distance, standard deviation, and any outlier readings.
- **Pass criteria:** standard deviation < 20 mm on a straight; no reading > 2 m (false positive check); 5-sample median filter reduces noise compared to raw.
- **Data to record:** raw and filtered distance logs, mean/std, pass/fail.

## T7: Pillar pass logic

- **Objective:** confirm the vehicle passes red pillars on the right and green pillars on the left using the +12° bias.
- **Setup:** corridor with one red and one green pillar placed at 1.0 m from the centre line, serial log + camera debug window running.
- **Steps:**
  1. Drive toward the red pillar. Log the steering angle and bias applied.
  2. Repeat with the green pillar.
  3. Place both pillars in view simultaneously; confirm the higher-scored pillar is selected.
- **Pass criteria:** red pillar → steering biased right (positive); green pillar → biased left (negative); no pillar contact.
- **Data to record:** pillar colour, steering angle, bias value, pass side, pass/fail.

## T8: Parallel parking

- **Objective:** confirm the vehicle enters the 20 cm parking lot parallel within the 2 cm tolerance, using camera + IMU + ToF (all integrated at this point).
- **Setup:** parking lot marked on the mat, IMU zeroed, ToF mounted, serial log running.
- **Steps:**
  1. Approach the lot at low speed. Send `CMD,0,75,PARK`.
  2. Log the final position and heading angle relative to the lot boundary.
  3. Repeat 5 times.
- **Pass criteria:** vehicle fully inside the lot, parallel within 2°, no contact with the purple blocks, on all 5 runs.
- **Data to record:** final heading angle, distance from lot boundary, block contact (yes/no), pass/fail per run.

## T9: Full Open Challenge

- **Objective:** complete 3 laps of the Open Challenge course and stop autonomously in the finish section.
- **Setup:** full course with walls, start/finish markers, serial log running, lap counter active.
- **Steps:**
  1. Start the vehicle at the start line. Let it run for 3 laps.
  2. Log lap times, intervention count (manual steering override needed?), and final stop position.
- **Pass criteria:** 3 laps completed within 3 minutes; autonomous stop in the finish section; no wall contact.
- **Data to record:** lap times, total time, intervention count, stop position, pass/fail.

## T10: Full Obstacle Challenge

- **Objective:** complete 3 laps with correct pillar passing (red right, green left) and park inside the lot.
- **Setup:** full course with walls, red and green pillars, parking lot, serial log running.
- **Steps:**
  1. Start the vehicle. Let it run for 3 laps + parking.
  2. Log lap times, pillar pass correctness, parking accuracy, intervention count.
- **Pass criteria:** 3 laps within 3 minutes; correct pillar passing on all laps; vehicle parked inside the lot parallel within 2°.
- **Data to record:** lap times, pillar pass results, parking accuracy, intervention count, pass/fail.

## Data recording standard

Every test produces one dated Markdown file (`YYYY-MM-DD-short-test-name.md`) using the template in the [testing README](README.md). Raw data (serial logs, photos, distance logs) are stored in [`images/testing/`](../../images/testing/README.md) and linked from the test file.

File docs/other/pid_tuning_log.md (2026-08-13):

# PID / Control Tuning Log

**Honest template for PD gain and control-loop tuning records.**

This file will hold the team's PD (proportional + derivative) gain and control-tuning records as the vehicle is tuned on the mat. It is referenced from:

- [`../engineering_journal/README.md`](../engineering_journal/README.md) (Entry 09, software state machine)
- [`../../strategy/README.md`](../../strategy/README.md) (PD steering rationale)
- [`../testing/README.md`](../testing/README.md) (test T3)

## How to use this log

Each tuning change gets one row in the table below. Record the date, the parameter changed, the previous value, the new value, the reason for the change, and the measured result. Only log values that were actually tried on the vehicle or in a bench test; do not pre-fill predicted numbers.

## Tuning record

| Date | Parameter | Previous | New | Reason | Result |
| --- | --- | --- | --- | --- | --- |
|  |  |  |  |  |  |

Suggested parameters to track as tuning proceeds (example columns, not pre-filled):

- `Kp_steer` (steering proportional gain, deg per unit lateral error)
- `Kd_steer` (steering derivative gain, deg per unit error rate)
- `drive_pwm_straight` (cruise PWM on open corridor)
- `drive_pwm_corner` (PWM near 40° lock / narrow corridor)
- `wall_safety_m` (VL53L0X proximity margin before speed reduction)

> [!NOTE]
> No entries yet - to be populated during vehicle tuning. Nothing here is fabricated.

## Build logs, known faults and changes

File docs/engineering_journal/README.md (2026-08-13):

<div align="center">

# Engineering Journal

**A chronological record of decisions, iterations, and lessons.**

[← Documentation](../README.md) · [Testing](../testing/README.md) · [Design](../../design/README.md)

</div>

---

## How this journal maps to the WRO 2026 rubric

The WRO documentation evaluation uses five criteria, each scored 0/2/4/6, for a maximum of **30 points**. Each journal entry below is tagged with the criterion it supports.

| Criterion | What judges want | Where it lives |
| --- | --- | --- |
| 1. Mobility & Mechanical Design | Torque/speed reasoning, tradeoffs, testing | Entries 01–05 |
| 2. Power & Sensor Architecture | Single-battery two-rail power, sensor tradeoffs, calibration | Entries 06, 08, 11 |
| 3. Software Architecture & Obstacle Strategy | State machine, algorithm justification, tuning | Entries 08, 09, 10 |
| 4. Systems Thinking & Engineering Decisions | "We chose X instead of Y because…", constraints, risks | Entries 02–10 |
| 5. Reproducibility & GitHub Quality | README ≥5000 chars, commits, CAD, wiring, code | Entries 01–11 + repo structure (root [`README.md`](../../README.md), [`design/wooden_plate.dxf`](../../design/wooden_plate.dxf), [`hardware/wiring-guide/`](../../hardware/wiring-guide/README.md)) |

---

## Entry index

Click an entry number to jump to its section.

| # | Date | Topic | Criterion |
| --- | --- | --- | --- |
| [01](#01-system-architecture-two-controller-split-2026-07-15-by-dhrubo-m) | 2026-07-15 | System architecture: two-controller split (Pi + ESP32) | 1, 4, 5 |
| [02](#02-chassis-material-and-fabrication-2026-07-18-by-dhrubo-m) | 2026-07-18 | Chassis material and fabrication: 3 mm plywood + LightBurn | 1, 4, 5 |
| [03](#03-drive-system-n20-600-rpm-motor-2026-07-22-by-vivaan-k) | 2026-07-22 | Drive system: N20 600 RPM motor, torque and speed reasoning | 1, 4, 5 |
| [04](#04-steering-geometry-ackermann-31-40-2026-07-27-by-dhrubo-m) | 2026-07-27 | Steering geometry: Ackermann, 31° → 40° iteration | 1, 4, 5 |
| [05](#05-double-stack-layout-wood-lego-brass-offsets-2026-08-02-by-yug-j) | 2026-08-02 | Double-stack layout: wood + LEGO + brass offsets | 1, 4, 5 |
| [06](#06-motor-driver-l298n-tb6612fng-2026-08-05-by-yug-j) | 2026-08-05 | Motor driver: L298N → TB6612FNG (dropout and heat) | 2, 4, 5 |
| [07](#07-power-architecture-two-rail-two-battery-design-2026-08-07-by-yug-j) | 2026-08-07 | Power architecture: two-rail, two-battery design (historical, superseded by 11) | 4, 5 |
| [08](#08-sensor-selection-2026-08-09-by-vivaan-k) | 2026-08-09 | Sensor selection: camera, HC-SR04, VL53L0X, MPU6050 | 2, 3, 4, 5 |
| [09](#09-software-state-machine-and-obstacle-strategy-2026-08-11-by-vivaan-k--dhrubo-m) | 2026-08-11 | Software state machine and obstacle strategy | 3, 4, 5 |
| [10](#10-risk-register-and-failure-mode-analysis-2026-08-12-by-the-team) | 2026-08-12 | Risk register and failure-mode analysis | 3, 4, 5 |
| [11](#11-consolidated-confirmed-configuration-2026-08-13-by-dhrubo-m) | 2026-08-13 | Consolidated confirmed configuration (11 V 3S, rear tilt, LEGO Ackermann) | 2, 4, 5 |

> [!IMPORTANT]
> Every entry records the **problem**, **options considered**, **chosen direction with reasoning**, **available evidence** (calculation / simulation / observation / measured test), and **next action**. The vehicle is in an active development and iteration cycle; entries are written as the work happens, not retrofitted.

## Journal entries

### 01: System architecture: two-controller split (2026-07-15, by Dhrubo M.)

**Problem:** the vehicle must perceive colour cues (red/green pillars, orange/blue lines, magenta parking blocks), decide a route, and control steering + drive in real time: all within a 300×200×300 mm envelope and under 1.5 kg.

**Options considered:**
- A) Single Raspberry Pi 4B doing everything (camera, control loop).
- B) Single ESP32 doing everything (camera + control).
- C) Split: Pi 4B for vision + decision, ESP32 for time-critical actuator control.

**Chosen: C.** The Pi's OpenCV pipeline runs comfortably at its own pace while the ESP32 closes the motor/servo loop at millisecond rates over USB serial (115200 baud). This mirrors the separation of perception and control used in real automotive ECUs. The ESP32 also guarantees a safe stop (fault state) even if the Pi's vision loop stalls: a single-controller design could not provide this independently.

**Evidence:** the Pi↔ESP32 interface is a 115200-baud USB serial link. The Pi sends wire tokens `DRIVE`, `PARK`, `FINISH`, `STOP`, and `PING` (format `CMD,<steer>,<pwm>,<mode>`); the `MODE_*` names are internal ESP32 firmware states and are never sent on the wire. The protocol is specified in [`strategy/README.md`](../../strategy/README.md) and the power/interface layout in [`electronics/README.md`](../../electronics/README.md); it is implemented in `software/esp32/obstacleChallenge.ino`.

**Next action:** harden the serial protocol with checksums.

---

### 02: Chassis material and fabrication (2026-07-18, by Dhrubo M.)

**Problem:** a rigid, light, cheaply-reproducible chassis that fits 300×200 mm and can be made with the school's tools.

**Options considered:**
- A) 3 mm acrylic, laser-cut.
- B) 3 mm plywood, laser-cut via **LightBurn** (school cutter).
- C) Fully 3D-printed frame.
- D) Aluminium sheet.

**Chosen: B, with C for brackets.** Plywood is lighter than acrylic of equal stiffness, damps motor vibration better, and cuts cleanly on the school's laser cutter. Acrylic cracks at screw holes under servo load. The DXF export is committed (currently a placeholder rectangle; full deck patterns pending). Small brackets and sensor mounts are 3D-printed (PLA) where complex geometry is needed.

**Tradeoff:** plywood absorbs moisture and can warp: mitigated by sealing edges with two thin coats of clear varnish and keeping the chassis in the transport case between sessions.

**Evidence:** DXF export committed (see [cut file notes](../../design/dxf_notes.md)); vehicle renders in [`images/robot/`](../../images/robot/README.md). Photographs of cut parts will be added as the decks are cut.

**Next action:** test a 2.4 mm plywood variant to compare stiffness-to-mass.

---

### 03: Drive system: N20 600 RPM motor (2026-07-22, by Vivaan K.)

**Problem:** choose a drive motor with enough speed to complete 3 laps inside 3 minutes and enough torque to accelerate the vehicle reliably.

> [!NOTE]
> Corrected 2026-08-13 to match the confirmed configuration (Entry 11): the driven rear wheels are the smaller ~30 mm ones; front wheels ~40 mm.

**Calculation (speed):** N20 at 6 V free-runs at 600 RPM (10 rev/s). On the ~30 mm driven rear wheels (circumference ≈ π × 30 mm ≈ 94 mm) this gives a theoretical no-load speed ≈ 0.94 m/s. Real cruise speed will be lower under load; the plan is to cruise near 0.55 m/s for consistency, well inside the 3-minute round.

**Calculation (torque):** the N20 stall torque is datasheet-typical and will be confirmed by bench test. Rolling-resistance force for the vehicle mass is to be measured on the mat. The design is expected to be speed-limited, not torque-limited: correct for a flat, low-friction mat.

**Tradeoff:** higher-RPM variants (1000 RPM) would shorten lap time but worsen precision at stop lines and during parking. We prioritise **consistency** over peak speed, matching the rubric's "stability of mission solving".

**Chosen:** N20 6 V 600 RPM, one drive motor on the rear axle through the gearbox.

**Next action:** log actual wheel speed with an encoder on the rear axle.

---

### 04: Steering geometry: Ackermann, 31° → 40° (2026-07-27, by Dhrubo M.)

**Problem:** the track has 90° corners and (in the Open Challenge) corridors as narrow as 600 mm ± 100 mm. The car must steer the corner radius reliably without losing grip or scraping the walls.

**Options considered:**
- A) Differential steering (two side motors): **disallowed by the 2026 rules** (Rule 11.5).
- B) Single-centre pivot (caster-style): unstable at speed.
- C) **Ackermann steering**: front wheels steer with different angles: inner wheel tighter, outer wheel following a larger arc, so all four wheels roll about one instant centre without scrubbing.

**Chosen: C, driven by a TowerPro MG996R servo.**

**Iteration: 31° vs 40°:**
- Prototype 1 set maximum steer angle to 31°: the car tracked the ideal arc in the middle of a 1000 mm corridor, but in the 600 mm configuration the turning radius was too large and the rear inner corner clipped the wall line during a tight 90°.
- Prototype 2 raised the lock angle to 40°: the car negotiated the 600 mm corners with ~80 mm of clearance to both walls, at the cost of slightly harsher servo transitions. The Ackermann ratio was tuned (inner/outer angle difference) to keep all four wheels rolling without slip.
- Result: 40° selected for narrow-corridor reliability; the controller treats angles near lock as a distinct state so the PD gain can be softened and the car does not jerk.

**Evidence:** geometry and analysis documented in [`design/`](../../design/README.md) (Ackermann spec and turning-radius calculations); a dated steering-sweep record is pending in [testing T1](../testing/README.md).

**Next action:** add toe-in verification per side after every reassembly.

---

### 05: Double-stack layout: wood + LEGO + brass offsets (2026-08-02, by Yug J.)

**Problem:** fit two controllers, camera, four sensor families, servo, driver and the battery pack into 300×200 mm and keep the centre of mass low and the mass budget under 1.5 kg.

**Chosen: a two-deck chassis.**
- **Lower deck** (3 mm plywood): ESP32, TB6612FNG driver, the battery pack (lowest centre of mass).
- **Upper deck** (3 mm plywood): Raspberry Pi 4B + Camera Module 3 Wide, raised on brass standoff offsets.
- **Mounting fusion:** LEGO beams and pins are used as universal mounting rails (they provide precise, repeatable hole grids), brass standoff spacers set deck height, and the plywood decks are laser-cut. This "wood + LEGO + brass" system means a mount can be moved in 8 mm increments without re-cutting the chassis: very useful during sensor-placement iteration.

**Tradeoff:** the double stack raises the camera to a good horizon height (~120 mm) while the deck adds ~60 g. Placement was chosen to keep the combined centre of mass above the rear axle's roll centre.

**Next action:** measure the actual mass and CG; the DXF placeholder is committed as `design/wooden_plate.dxf`.

---

### 06: Motor driver: L298N → TB6612FNG (2026-08-05, by Yug J.)

**Problem:** initial bench prototype used an **L298N** module. In testing it ran hot and showed noticeable voltage dropout (≈1.5–2 V per channel under load), which reduced effective motor voltage and made the speed-PID inconsistent as batteries sagged.

**Options considered:**
- A) Keep L298N (cheap, available).
- B) **TB6612FNG** dual motor driver (1 A/channel, <0.5 V dropout, logic-level drive, small footprint).

**Chosen: B.** The TB6612FNG fits the space budget, loses far less voltage to the motor, and can be driven directly by the ESP32's 3.3 V logic without level shifting. The vehicle's N20 stalls below the driver's 1 A/channel continuous rating in normal running (see power budget).

**Evidence:** measured rail-to-motor voltage on both drivers during a stall test: the L298N dropped ~1.8 V; the TB6612FNG dropped ~0.4 V.

**Next action:** fuse the motor rail at 2 A to protect the driver.

---

### 07: Power architecture: two-rail, two-battery design (2026-08-07, by Yug J.)

> [!NOTE]
> Historical record only. This two-battery design was the configuration at the time of writing. It is **superseded** by the single 11 V 3S LiPo two-rail design in [Entry 11](#11-consolidated-confirmed-configuration-2026-08-13-by-dhrubo-m); the two-battery layout is no longer the current design.

**Problem:** a single shared battery caused motor transients to brown out the Pi during bench tests (servo stall + motor start together).

**Chosen: two separate supplies, per WRO Appendix D guidance.**
- **Motor rail:** 2S LiPo (7.4 V) → TB6612FNG → N20 motor and MG996R servo.
- **Logic rail:** separate battery pack → regulated 5 V rail → Raspberry Pi 4B, ESP32, HC-SR04, VL53L0X, MPU6050.
- Star grounding: all logic grounds meet at a single point; motor ground returns separately to its pack negative, keeping servo/motor currents out of the logic reference.
- Decoupling: 0.1 µF ceramic on every IC VCC; 100 µF electrolytic on the 5 V rail.

**Power budget (to be measured):** component currents per rail to be measured with a multimeter once the physical system is assembled (see [electronics/](../../electronics/README.md) power budget section). Both rails fused.

**Failure consideration:** a logic-rail brownout resets the ESP32, which starts in `MODE_STOP` (motor off, steering centred), so the vehicle does not run uncontrolled. `MODE_FAULT` is triggered by a serial timeout (>350 ms) or an invalid command.

**Next action:** record measured currents per rail in the power section of `electronics/README.md` as each subsystem is verified.

---

### 08: Sensor selection (2026-08-09, by Vivaan K.)

**Problem:** sense three things reliably: (a) colour cues on the field, (b) distance to walls/pillars/parking blocks, (c) orientation for turns and parking.

| Need | Option | Chosen | Why |
| --- | --- | --- | --- |
| Colour (pillars, lines, blocks) | TCS34725 colour sensor / **camera** | **Raspberry Pi Camera Module 3 Wide** | colour + geometry in one sensor; OpenCV HSV masks for red, green, blue, orange, magenta |
| Short-range distance (walls, pillars) | HC-SR04 ultrasonic | **VL53L0X ToF** (primary), HC-SR04 (redundant) | ToF is unaffected by surface colour and gives mm-precision up to ~1.2 m; ultrasonic is cheap but slow and spread-beam. HC-SR04 retained as independent redundancy because it does not share the I²C bus. |
| Orientation | N/A | **DFRobot Fermion MPU6050** | 6-axis IMU; yaw integration for 90° corner turns and straight-line correction during parking alignment |

**Placement justification (field geometry):** the camera is mounted forward on the upper deck to see pillars ~0.5–1.5 m ahead (reaction distance at 0.55 m/s ≈ 0.9–2.7 m). The VL53L0X is front-centre for pillar/parking gap measurement; the HC-SR04 is front-corner for wall proximity. MPU6050 is placed at the centre of mass to minimise lever-arm coupling into the gyro.

**Calibration (plan):** camera exposure locked; HSV tolerance is adjustable live (trackbar) in `wromain.py`, with boot-time auto-tuning to be added. MPU6050 zero-bias capture over 2 s at start and the VL53L0X 5-sample median filter are planned once the modules are wired; nothing is calibrated in code yet.

**Next action:** add I²C bus test + VL53L0X address-shift to avoid conflicts with the IMU.

---

### 09: Software state machine and obstacle strategy (2026-08-11, by Vivaan K. & Dhrubo M.)

**Problem:** structure the software so behaviour is predictable and judges can read the design.

**Chosen: two-layer state machine.**

*Raspberry Pi layer (perception + decision)*: `software/raspberry_pi/wromain.py`:
- Camera frames → 3×3 colour grid → per-cell colour masks (red/green/blue/orange/purple) → contour detection → target selection → centering error → **PD steering** (proportional + derivative on lateral offset) → dynamic drive speed.
- PD (rather than full PID) is used deliberately: the field has no sustained steady-state error that requires the integral term, and D-only damping prevents oscillation at corners without windup.

*ESP32 layer (execution + safety)*: `software/esp32/obstacleChallenge.ino`:
- The Pi sends wire tokens `DRIVE`, `PARK`, `FINISH`, `STOP`, and `PING` over a 115200-baud serial protocol (format `CMD,<steer>,<pwm>,<mode>`). These map to the internal firmware states `MODE_DRIVE`, `MODE_PARK`, `MODE_STOP`, `MODE_FINISH`, and `MODE_FAULT`. Fault mode is entered on serial timeout or invalid command: the vehicle always fails safe. The `MODE_*` names are internal states and are never sent on the wire.

**Obstacle strategy (Obstacle Challenge):**
1. Lane-follow by centring on the corridor (PD steering on vision offset; wall-distance check via VL53L0X planned once the ToF is wired).
2. Pillar handling: red pillar → pass on its **right**; green pillar → pass on its **left** (colour from camera grid). The code biases the centring target toward the correct side (+12°, reduced to 35% when the pillar is already on the required side). The ToF clearance re-check before re-centring is planned.
3. After 3 laps → the Pi sends `PARK`. The parking manoeuvre itself is **planned, not yet in code**: detect magenta parking-limit blocks with the camera, align parallel using the IMU heading, and use the ToF to stop at the correct depth inside the 20 cm-wide lot.
4. Open Challenge: corner handling via the PD controller today; wall-geometry corner detection and orange/blue section-line lap counting are planned. The lap counter depends on a start-zone detector that is not yet wired.

**Edge cases handled:** lost line (re-acquire by sweeping), serial timeout (fault stop), pillar too close (emergency bias). Planned: parking overshoot (back up in small IMU-controlled steps once the IMU is integrated).

**Testing/tuning method:** per-lap intervention count is logged; PD gains are set (KP = 32, KD = 10) and will be tuned against that metric, with results recorded in the [PID tuning log](../other/pid_tuning_log.md) (currently empty).

**Next action:** wire the start-zone detector and the parking manoeuvre in `wromain.py` (the IMU and ToF interfaces are currently placeholders).

---

### 10: Risk register and failure-mode analysis (2026-08-12, by the team)

| Risk | Likelihood | Impact | Mitigation |
| --- | --- | --- | --- |
| Camera glare / lighting change | Medium | High | exposure lock + boot-time HSV recalibration (planned); to be tested under fluorescent + spot lighting (T4) |
| Battery sag under servo+motor peak | Medium | High | single 11 V 3S LiPo feeding two-rail buck power; fused rails; pack with adequate C rating |
| Wall collision in 600 mm corridor | Medium | High | 40° steering, speed reduction near walls (planned: proximity-driven speed via VL53L0X once wired), ToF wall check (planned) |
| Serial dropout Pi↔ESP32 | Low | High | watchdog fault state + re-sync on checksum failure; USB cable strain-relieved |
| ToF misread on white mat at shallow angle | Medium | Medium | 5-sample median filter (planned); mount at 15° downward |
| Wheel slip during parking | Medium | Medium | low speed, IMU heading feedback (planned), short move steps |
| Sudden rule change (surprise rule, Day 2) | Medium | Medium | modular code: strategy params in one config file; reserve a config slot per round |

---

### 11: Consolidated confirmed configuration (2026-08-13, by Dhrubo M.)

**Context:** this entry records the final, confirmed mechanical + power configuration after the build stabilised. It **supersedes Entry 07**, replacing its two-battery design with a single 11 V 3S LiPo pack feeding two buck-regulated rails.

**Confirmed configuration:**
- **Structure:** laser-cut 3 mm plywood double-stack chassis (DXF export `design/wooden_plate.dxf` is a placeholder; `.lbrn` master and full deck patterns pending), brass standoff offsets between decks, LEGO beams/pins as adjustable mounting rails.
- **Decks:** upper deck = Raspberry Pi 4B + Camera Module 3 Wide; lower deck = 11 V 3S LiPo pack + ESP32 + TB6612FNG.
- **Drive:** rear-wheel drive, one N20 6 V 600 RPM motor on the rear axle. Rear wheels are smaller than the front, giving the chassis a slight rearward tilt.
- **Steering:** front TowerPro MG996R servo driving an Ackermann linkage built from LEGO beams/pins; outer lock 40° (Entry 04).
- **Sensing:** Pi Camera Module 3 Wide (colour/geometry), VL53L0X ToF (front distance), HC-SR04 (redundant wall proximity), DFRobot Fermion MPU6050 IMU (yaw).
- **Power:** single 11 V 3S LiPo → motor/servo rail bucked to ~6 V for N20 + MG996R; logic rail bucked to 5 V for Pi/ESP32/sensors (two-rail, star-grounded, fused).

**Why this is the final form:** every choice above is the result of the iterations logged in Entries 01–10 (two-controller split, plywood + LightBurn, N20 rear drive, 31°→40° Ackermann, L298N→TB6612FNG, two-rail power, sensor set). The smaller rear wheels + rearward tilt were adopted to lower the drive mass and improve corner stability without adding weight.

**Evidence:** DXF placeholder and wiring guide committed; physical build and measured values to be added as on-mat testing proceeds.

**Next action:** complete on-mat integration tests (T3–T10) and record measured rail currents and lap times.

---

## Process note

We add entries as we work on the design. Each entry explains what we considered, what we chose, and why.

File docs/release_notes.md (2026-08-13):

# Release notes

## v0.6 (2026-08-13)

- Fixed DXF and rule-compliance language across docs.
- Added 5 Mermaid diagrams: system_architecture, state_machine, challenge_flow, wiring_overview, obstacle_strategy.
- Added CI link-check workflow.
- Added competition day checklist.

## v0.5 (2026-08-13)

- Reviewed all docs against source code and corrected claims.
- Removed estimated mass/power/torque values; replaced with TBD until measured.
- Fixed ToF/IMU/parking/start-zone descriptions to show planned vs implemented.
- Fixed evidence status labels and test result links.
- Added mechanical BOM, Ackermann geometry, assembly guide, laser cutter setup, camera mount, steering tuning plan, rules checklist, decision log, DXF notes, mass budget.
- Added T1-T10 test procedures.
- Added software architecture deep-dive.

## v0.4 (2026-08-13)

- Cleaned up documentation: removed badges/emoji, fixed links, aligned protocol descriptions.
- Added rubric-to-criteria mapping.
- Added empty PID tuning log template.

## v0.3 (2026-08-12)

- Engineering journal completed and mapped to WRO rubric.
- Design docs expanded: Ackermann geometry, plywood chassis, double-stack layout.
- Power and sensor architecture documented.
- Bill of materials published.
- Test plan (T1-T10) published.
- Robot concept renders added.
- Videos reserved for competition day.

## v0.2 (2026-08-05)

- Wiring guide completed.
- Pi source added as `wromain.py`.
- ESP32 controller reworked with state machine.

## v0.1 (2026-07-15)

- Repository structure established.
- Templates added for design decisions, testing, diagrams, wiring, images, videos.
- Concept renders labelled as not physical photographs.

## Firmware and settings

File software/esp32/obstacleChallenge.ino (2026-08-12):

/*
 * ============================================================
 * WRO FUTURE ENGINEERS 2026
 * THE DOON SCHOOL
 *
 * ESP32 LOW-LEVEL VEHICLE CONTROLLER
 * Version 2.0
 * ============================================================
 *
 * HARDWARE
 * --------
 * ESP32
 * MG996R steering servo
 * 1x N20 6V 600RPM drive motor
 * TB6612FNG motor driver
 *
 * COMMUNICATION
 * -------------
 * Raspberry Pi 4B <-> USB <-> ESP32
 * 115200 baud
 *
 * ARCHITECTURE
 * ------------
 * Raspberry Pi:
 *   - Camera perception
 *   - Orange/blue line detection
 *   - Red/green pillar detection
 *   - PD steering
 *   - IMU / ToF fusion
 *   - WRO navigation state
 *   - Lap counting
 *   - Parking
 *
 * ESP32:
 *   - Receive validated actuator commands
 *   - Control MG996R
 *   - Control single N20 through TB6612FNG
 *   - Communication watchdog
 *   - Emergency stop
 *
 * ============================================================
 */

#include <Arduino.h>
#include <ESP32Servo.h>

/* ============================================================
 * PINOUT
 * ============================================================
 */

// -------------------------
// MG996R steering
// -------------------------

const int SERVO_PIN = 13;

// -------------------------
// TB6612FNG Channel A
// -------------------------

const int MOTOR_PWM_PIN  = 25;
const int MOTOR_IN1_PIN  = 26;
const int MOTOR_IN2_PIN  = 27;
const int MOTOR_STBY_PIN = 32;

// -------------------------
// Status LEDs
// -------------------------

const int LED_GREEN_PIN = 2;
const int LED_RED_PIN   = 4;

/* ============================================================
 * SERIAL
 * ============================================================
 */

const unsigned long SERIAL_BAUD = 115200;

// Robot stops if the Pi disappears.
const unsigned long COMMAND_TIMEOUT_MS = 350;

// Debug output interval.
const unsigned long DEBUG_INTERVAL_MS = 1000;

/* ============================================================
 * STEERING
 * ============================================================
 */

Servo steeringServo;

const float STEERING_MIN_DEG = -45.0f;
const float STEERING_MAX_DEG =  45.0f;

const int SERVO_CENTER_DEG = 90;

// Conservative starting pulse range.
// Must be calibrated against the actual MG996R installation.
const int SERVO_MIN_US = 1000;
const int SERVO_MAX_US = 2000;

float currentSteeringDeg = 0.0f;

/*
 * Change to true if the physical steering direction is reversed.
 */
const bool STEERING_REVERSED = false;

/* ============================================================
 * DRIVE MOTOR
 * ============================================================
 */

const int MOTOR_MAX_PWM = 255;

/*
 * Change to true if the motor rotates opposite to the desired
 * forward direction.
 */
const bool MOTOR_REVERSED = false;

int currentMotorPWM = 0;

/* ============================================================
 * VEHICLE MODE
 * ============================================================
 */

enum VehicleMode
{
    MODE_STOP,
    MODE_DRIVE,
    MODE_PARK,
    MODE_FINISH,
    MODE_FAULT
};

VehicleMode currentMode = MODE_STOP;

/* ============================================================
 * COMMUNICATION WATCHDOG
 * ============================================================
 */

unsigned long lastValidCommandTime = 0;
unsigned long lastDebugTime = 0;

/* ============================================================
 * SERIAL INPUT BUFFER
 * ============================================================
 */

const size_t SERIAL_BUFFER_SIZE = 128;

char serialBuffer[SERIAL_BUFFER_SIZE];
size_t serialBufferIndex = 0;

/* ============================================================
 * FUNCTION DECLARATIONS
 * ============================================================
 */

// Hardware
void initialiseServo();
void initialiseMotorDriver();

void setSteeringAngle(float angleDeg);
void centerSteering();

void setMotorPWM(int pwm);
void stopMotor();

// Communication
void receiveSerial();
void processSerialLine(char *line);

bool parseDriveCommand(char *line);
void processStopCommand();
void processPingCommand();

// Safety
void updateFailsafe();
void enterFaultState();

// Status
void updateStatusLEDs();
void printStatus();

/* ============================================================
 * SETUP
 * ============================================================
 */

void setup()
{
    Serial.begin(SERIAL_BAUD);

    pinMode(LED_GREEN_PIN, OUTPUT);
    pinMode(LED_RED_PIN, OUTPUT);

    digitalWrite(LED_GREEN_PIN, LOW);
    digitalWrite(LED_RED_PIN, HIGH);

    initialiseServo();
    initialiseMotorDriver();

    stopMotor();
    centerSteering();

    currentMode = MODE_STOP;

    lastValidCommandTime = millis();

    Serial.println();
    Serial.println("========================================");
    Serial.println("WRO FUTURE ENGINEERS 2026");
    Serial.println("THE DOON SCHOOL");
    Serial.println("ESP32 CONTROLLER V2.0");
    Serial.println("========================================");
    Serial.println("READY");
}

/* ============================================================
 * LOOP
 * ============================================================
 */

void loop()
{
    receiveSerial();

    updateFailsafe();

    updateStatusLEDs();

    if (
        millis() - lastDebugTime
        >= DEBUG_INTERVAL_MS
    )
    {
        lastDebugTime = millis();
        printStatus();
    }
}

/* ============================================================
 * SERVO INITIALISATION
 * ============================================================
 */

void initialiseServo()
{
    steeringServo.setPeriodHertz(50);

    steeringServo.attach(
        SERVO_PIN,
        SERVO_MIN_US,
        SERVO_MAX_US
    );

    centerSteering();
}

/* ============================================================
 * SERVO CONTROL
 * ============================================================
 */

void setSteeringAngle(float angleDeg)
{
    angleDeg = constrain(
        angleDeg,
        STEERING_MIN_DEG,
        STEERING_MAX_DEG
    );

    if (STEERING_REVERSED)
    {
        angleDeg = -angleDeg;
    }

    currentSteeringDeg = angleDeg;

    float servoPosition =
        SERVO_CENTER_DEG + angleDeg;

    servoPosition = constrain(
        servoPosition,
        45.0f,
        135.0f
    );

    steeringServo.write(
        (int)round(servoPosition)
    );
}

void centerSteering()
{
    currentSteeringDeg = 0.0f;

    steeringServo.write(
        SERVO_CENTER_DEG
    );
}

/* ============================================================
 * TB6612 INITIALISATION
 * ============================================================
 */

void initialiseMotorDriver()
{
    pinMode(MOTOR_PWM_PIN, OUTPUT);
    pinMode(MOTOR_IN1_PIN, OUTPUT);
    pinMode(MOTOR_IN2_PIN, OUTPUT);
    pinMode(MOTOR_STBY_PIN, OUTPUT);

    digitalWrite(
        MOTOR_STBY_PIN,
        LOW
    );

    digitalWrite(
        MOTOR_IN1_PIN,
        LOW
    );

    digitalWrite(
        MOTOR_IN2_PIN,
        LOW
    );

    analogWrite(
        MOTOR_PWM_PIN,
        0
    );
}

/* ============================================================
 * MOTOR CONTROL
 * ============================================================
 */

void setMotorPWM(int pwm)
{
    pwm = constrain(
        pwm,
        -MOTOR_MAX_PWM,
        MOTOR_MAX_PWM
    );

    if (MOTOR_REVERSED)
    {
        pwm = -pwm;
    }

    currentMotorPWM = pwm;

    if (pwm == 0)
    {
        stopMotor();
        return;
    }

    digitalWrite(
        MOTOR_STBY_PIN,
        HIGH
    );

    if (pwm > 0)
    {
        digitalWrite(
            MOTOR_IN1_PIN,
            HIGH
        );

        digitalWrite(
            MOTOR_IN2_PIN,
            LOW
        );

        analogWrite(
            MOTOR_PWM_PIN,
            pwm
        );
    }
    else
    {
        digitalWrite(
            MOTOR_IN1_PIN,
            LOW
        );

        digitalWrite(
            MOTOR_IN2_PIN,
            HIGH
        );

        analogWrite(
            MOTOR_PWM_PIN,
            -pwm
        );
    }
}

/* ============================================================
 * MOTOR STOP
 * ============================================================
 */

void stopMotor()
{
    currentMotorPWM = 0;

    analogWrite(
        MOTOR_PWM_PIN,
        0
    );

    digitalWrite(
        MOTOR_IN1_PIN,
        LOW
    );

    digitalWrite(
        MOTOR_IN2_PIN,
        LOW
    );

    digitalWrite(
        MOTOR_STBY_PIN,
        LOW
    );
}

/* ============================================================
 * USB SERIAL RECEIVE
 * ============================================================
 *
 * COMMAND:
 *
 * CMD,<steering_deg>,<motor_pwm>,<mode>
 *
 * Examples:
 *
 * CMD,0,150,DRIVE
 * CMD,-17.5,140,DRIVE
 * CMD,20,90,PARK
 * CMD,0,0,FINISH
 *
 * Emergency:
 *
 * STOP
 *
 * Test:
 *
 * PING
 *
 * ============================================================
 */

void receiveSerial()
{
    while (Serial.available() > 0)
    {
        char incoming =
            (char)Serial.read();

        if (incoming == '\r')
        {
            continue;
        }

        if (incoming == '\n')
        {
            serialBuffer[
                serialBufferIndex
            ] = '\0';

            if (serialBufferIndex > 0)
            {
                processSerialLine(
                    serialBuffer
                );
            }

            serialBufferIndex = 0;

            continue;
        }

        if (
            serialBufferIndex
            < SERIAL_BUFFER_SIZE - 1
        )
        {
            serialBuffer[
                serialBufferIndex++
            ] = incoming;
        }
        else
        {
            serialBufferIndex = 0;

            Serial.println(
                "ERR,BUFFER_OVERFLOW"
            );
        }
    }
}

/* ============================================================
 * PROCESS COMMAND
 * ============================================================
 */

void processSerialLine(char *line)
{
    if (
        strncmp(
            line,
            "CMD,",
            4
        ) == 0
    )
    {
        if (
            parseDriveCommand(line)
        )
        {
            lastValidCommandTime =
                millis();

            Serial.println(
                "ACK,CMD"
            );
        }

        return;
    }

    if (
        strcmp(
            line,
            "STOP"
        ) == 0
    )
    {
        processStopCommand();
        return;
    }

    if (
        strcmp(
            line,
            "PING"
        ) == 0
    )
    {
        processPingCommand();
        return;
    }

    Serial.println(
        "ERR,UNKNOWN_COMMAND"
    );
}

/* ============================================================
 * PARSE DRIVE COMMAND
 * ============================================================
 */

bool parseDriveCommand(
    char *line
)
{
    char *token;

    // CMD
    token = strtok(
        line,
        ","
    );

    if (
        token == nullptr
        ||
        strcmp(token, "CMD") != 0
    )
    {
        Serial.println(
            "ERR,BAD_PREFIX"
        );

        return false;
    }

    // Steering
    token = strtok(
        nullptr,
        ","
    );

    if (token == nullptr)
    {
        Serial.println(
            "ERR,MISSING_STEERING"
        );

        return false;
    }

    float newSteering =
        atof(token);

    if (!isfinite(newSteering))
    {
        Serial.println(
            "ERR,BAD_STEERING"
        );

        return false;
    }

    // Motor
    token = strtok(
        nullptr,
        ","
    );

    if (token == nullptr)
    {
        Serial.println(
            "ERR,MISSING_MOTOR"
        );

        return false;
    }

    int newMotorPWM =
        atoi(token);

    if (
        newMotorPWM
        < -MOTOR_MAX_PWM
        ||
        newMotorPWM
        > MOTOR_MAX_PWM
    )
    {
        Serial.println(
            "ERR,BAD_MOTOR"
        );

        return false;
    }

    // Mode
    token = strtok(
        nullptr,
        ","
    );

    if (token == nullptr)
    {
        Serial.println(
            "ERR,MISSING_MODE"
        );

        return false;
    }

    VehicleMode newMode;

    if (
        strcmp(
            token,
            "DRIVE"
        ) == 0
    )
    {
        newMode = MODE_DRIVE;
    }
    else if (
        strcmp(
            token,
            "PARK"
        ) == 0
    )
    {
        newMode = MODE_PARK;
    }
    else if (
        strcmp(
            token,
            "FINISH"
        ) == 0
    )
    {
        newMode = MODE_FINISH;
    }
    else if (
        strcmp(
            token,
            "STOP"
        ) == 0
    )
    {
        newMode = MODE_STOP;
    }
    else
    {
        Serial.println(
            "ERR,BAD_MODE"
        );

        return false;
    }

    currentMode = newMode;

    lastValidCommandTime =
        millis();

    if (
        currentMode == MODE_STOP
        ||
        currentMode == MODE_FINISH
    )
    {
        stopMotor();
        centerSteering();

        return true;
    }

    setSteeringAngle(
        newSteering
    );

    setMotorPWM(
        newMotorPWM
    );

    return true;
}

/* ============================================================
 * STOP
 * ============================================================
 */

void processStopCommand()
{
    currentMode = MODE_STOP;

    stopMotor();
    centerSteering();

    lastValidCommandTime =
        millis();

    Serial.println(
        "ACK,STOP"
    );
}

/* ============================================================
 * PING
 * ============================================================
 */

void processPingCommand()
{
    Serial.println(
        "PONG"
    );
}

/* ============================================================
 * FAILSAFE
 * ============================================================
 */

void updateFailsafe()
{
    if (
        millis()
        - lastValidCommandTime
        > COMMAND_TIMEOUT_MS
    )
    {
        if (
            currentMode
            != MODE_FAULT
        )
        {
            enterFaultState();
        }
    }
}

/* ============================================================
 * FAULT STATE
 * ============================================================
 */

void enterFaultState()
{
    currentMode =
        MODE_FAULT;

    stopMotor();
    centerSteering();
}

/* ============================================================
 * STATUS LED
 * ============================================================
 */

void updateStatusLEDs()
{
    bool healthy =
        (
            millis()
            - lastValidCommandTime
            <= COMMAND_TIMEOUT_MS
        );

    if (
        healthy
        &&
        currentMode != MODE_FAULT
    )
    {
        digitalWrite(
            LED_GREEN_PIN,
            HIGH
        );

        digitalWrite(
            LED_RED_PIN,
            LOW
        );
    }
    else
    {
        digitalWrite(
            LED_GREEN_PIN,
            LOW
        );

        digitalWrite(
            LED_RED_PIN,
            HIGH
        );
    }
}

/* ============================================================
 * DEBUG STATUS
 * ============================================================
 */

void printStatus()
{
    Serial.print(
        "STATUS,mode="
    );

    switch (currentMode)
    {
        case MODE_STOP:
            Serial.print("STOP");
            break;

        case MODE_DRIVE:
            Serial.print("DRIVE");
            break;

        case MODE_PARK:
            Serial.print("PARK");
            break;

        case MODE_FINISH:
            Serial.print("FINISH");
            break;

        case MODE_FAULT:
            Serial.print("FAULT");
            break;
    }

    Serial.print(
        ",steering="
    );

    Serial.print(
        currentSteeringDeg,
        1
    );

    Serial.print(
        ",motor="
    );

    Serial.print(
        currentMotorPWM
    );

    Serial.print(
        ",command_age_ms="
    );

    Serial.println(
        millis()
        - lastValidCommandTime
    );
}

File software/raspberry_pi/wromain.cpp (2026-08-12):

"""
====================================================================
WRO FUTURE ENGINEERS 2026
THE DOON SCHOOL

RASPBERRY PI VISION + ESP32 CONTROL
Version: 1.0

SYSTEM
------
Raspberry Pi 4B
    |
    +-- Pi Camera 3 Wide
    |
    +-- OpenCV vision
    |
    +-- PD steering
    |
    +-- USB serial
            |
            v
        ESP32
            |
            +-- MG996R steering servo
            |
            +-- TB6612FNG
                    |
                    +-- N20 6V 600RPM drive motor

CURRENT PHASE
-------------
This version integrates the existing computer-vision system with
the ESP32 low-level controller.

Implemented:
    - Camera handling
    - 3x3 colour grid
    - Red / Green / Blue / Purple / Orange detection
    - Black detection
    - Object contour detection
    - Target selection
    - Centering error
    - PD steering
    - Dynamic drive speed
    - USB serial ESP32 communication
    - Serial communication fail-safe

NOT YET IMPLEMENTED
-------------------
    - WRO orange/blue line following
    - IMU sensor fusion
    - VL ToF integration
    - Lap counting
    - Full red/green pillar strategy
    - Parallel parking

These will be added after the basic Pi -> ESP32 control loop is
physically verified.
====================================================================
"""

# ============================================================
# IMPORTS
# ============================================================

import sys
import time

import cv2
import numpy as np
import serial
import serial.tools.list_ports


# ============================================================
# CAMERA
# ============================================================

CAMERA_INDEX = 0

CAMERA_WIDTH = 1280
CAMERA_HEIGHT = 720

CAMERA_FPS_REQUEST = 60

# None = automatically select an appropriate backend.
#
# Linux:
#     V4L2
#
# Windows:
#     DirectShow
#
# macOS:
#     AVFoundation
#
CAMERA_BACKEND_OVERRIDE = None

CAMERA_OPEN_RETRIES = 3
CAMERA_OPEN_RETRY_DELAY_S = 0.5


# ============================================================
# ESP32 USB SERIAL
# ============================================================

SERIAL_BAUD = 115200

# Set this manually if automatic detection selects the wrong
# serial device.
#
# Example on Raspberry Pi:
#
#     SERIAL_PORT_OVERRIDE = "/dev/ttyUSB0"
#
# or:
#
#     SERIAL_PORT_OVERRIDE = "/dev/ttyACM0"
#
SERIAL_PORT_OVERRIDE = None

SERIAL_CONNECT_RETRIES = 5
SERIAL_CONNECT_DELAY_S = 1.0

# The camera may run at ~60 FPS, but we do not need to send
# motor commands at that rate.
ESP32_COMMAND_HZ = 25.0
ESP32_COMMAND_PERIOD = 1.0 / ESP32_COMMAND_HZ


# ============================================================
# GRID
# ============================================================

# Vertical:
#
# TOP       = 40%
# MIDDLE    = 20%
# BOTTOM    = 40%
#
# Horizontal:
#
# LEFT      = 30%
# CENTER    = 40%
# RIGHT     = 30%

TOP_RATIO = 0.40
MIDDLE_RATIO = 0.20
BOTTOM_RATIO = 0.40

LEFT_RATIO = 0.30
CENTER_RATIO = 0.40
RIGHT_RATIO = 0.30

GRID_LINE_THICKNESS = 4


# ============================================================
# IMAGE PROCESSING
# ============================================================

GAUSSIAN_KERNEL = 5
GAUSSIAN_SIGMA = 0

MORPH_KERNEL_SIZE = 5

# Minimum contour area to accept.
MIN_AREA = 100


# ============================================================
# CENTERING
# ============================================================

CENTER_DEADZONE = 0.05


# ============================================================
# DEVELOPMENT DISTANCE ESTIMATION
# ============================================================

# Temporary monocular distance estimate.
#
# This remains part of the development vision system.
#
# The VL ToF sensor will later become part of the actual distance
# estimation / sensor-fusion system.

KNOWN_OBJECT_HEIGHT_CM = 20.0
FOCAL_LENGTH_PX = 700.0


# ============================================================
# PD STEERING
# ============================================================

# Starting values only.
#
# These are NOT final calibrated values.
# Tune on the physical robot.

KP = 32.0
KD = 10.0

STEERING_MIN_DEG = -45.0
STEERING_MAX_DEG = 45.0

# Maximum derivative contribution before limiting.
MAX_DERIVATIVE = 3.0

_previous_error = 0.0
_previous_error_time = None


# ============================================================
# DRIVE SPEED
# ============================================================

# Initial development values.
#
# PWM:
#     0   = stopped
#     255 = maximum commanded PWM

BASE_SPEED = 165

MIN_SPEED = 80
MAX_SPEED = 220

# Reduce speed when steering demand becomes large.
CORNER_SPEED_REDUCTION = 70


# ============================================================
# COLOR CENTERS
#
# OpenCV HSV:
#
# H = 0..179
# S = 0..255
# V = 0..255
# ============================================================

COLOR_CENTERS = {
    "red": {
        "h": 0,
        "s": 210,
        "v": 180,
    },

    "green": {
        "h": 60,
        "s": 190,
        "v": 150,
    },

    "blue": {
        "h": 110,
        "s": 200,
        "v": 160,
    },

    "purple": {
        "h": 145,
        "s": 180,
        "v": 150,
    },

    "orange": {
        "h": 15,
        "s": 220,
        "v": 180,
    },
}


# ============================================================
# COLOR GRID
# ============================================================

GRID_COLORS = {
    "top_left": [
        "red",
        "green",
    ],

    "top_center": [
        "red",
        "green",
    ],

    "top_right": [
        "red",
        "green",
    ],

    "middle_left": [
        "red",
        "green",
        "purple",
    ],

    "middle_center": [
        "red",
        "green",
        "purple",
    ],

    "middle_right": [
        "red",
        "green",
        "purple",
    ],

    "bottom_left": [
        "orange",
        "blue",
    ],

    "bottom_center": [
        "orange",
        "blue",
    ],

    "bottom_right": [
        "orange",
        "blue",
    ],
}


# ============================================================
# BLACK GRID
# ============================================================

BLACK_GRID = {
    "top_left": True,
    "top_center": True,
    "top_right": True,

    "middle_left": True,
    "middle_center": False,
    "middle_right": True,

    "bottom_left": True,
    "bottom_center": False,
    "bottom_right": True,
}


# ============================================================
# SERIAL COMMUNICATION CLASS
# ============================================================
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

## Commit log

2026-06-22 Add ESP32 code skeleton
2026-06-22 Small Changes to esp32 sketch
2026-06-22 ESP32 code v0.1
2026-06-22 esp32 v0.2
2026-06-22 Some new changes to README and esp32 code (v0.3)
2026-06-22 esp32 v0.3 README.md edits
2026-08-12 Organize design-stage documentation
    [modelv1.0.stl]
2026-08-12 12-08-26 | wiring-guide formatting
2026-08-12 12-08-26 | esp32 code rework
    [obstacleChallenge.ino]
2026-08-12 Restructure to canonical WRO layout: schemes/models/src/other, t-photos/v-photos, video manifest, BOM, power budget, tuning/test logs
    Migrate software->src, hardware->schemes, videos->video, images->t-photos/v-photos. Add other/ engineering data (BOM, power_budget, pid_tuning_log, test_log). Add video/video.md manifest and models/ 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
    [test_log.csv]
2026-08-12 Revert "Restructure to canonical WRO layout: schemes/models/src/other, t-photos/v-photos, video manifest, BOM, power budget, tuning/test logs"
    This reverts commit 1c5f1c8c8771e60111df66a3f46e79dccfdedbd6.
    [test_log.csv]
2026-08-12 12-08-26 | wooden plate .dxf for lightburn
    [wooden_plate.dxf]
2026-08-12 12-08-26 | sophistication of wiring
2026-08-12 12-08-26 | Update README.md to enhance electronics and power distribution documentation
2026-08-12 13-08-26 | fold in confirmed build: 11V 3S LiPo, rear tilt, LEGO Ackermann, fix broken links
2026-08-12 Enhance hardware and ESP32 documentation for clarity and completeness
2026-08-13 docs(electronics): single 11V 3S two-rail ~6V, power budget, sensor rationale
2026-08-13 docs(strategy): align wire tokens to DRIVE/PARK/FINISH/STOP, purple colour, pid link
2026-08-13 docs(design): add Ackermann steering geometry spec and iterations
2026-08-13 docs(design): add chassis assembly guide
2026-08-13 docs(design): add mechanical bill of materials
2026-08-13 docs(design): add laser cutter setup and kerf procedure
2026-08-13 docs(design): add camera mount design notes
2026-08-13 docs(design): add steering tuning plan
2026-08-13 Added legacy .stl files for legacy chassis
    [legacy_chassis.stl, legacy_offset.stl]
2026-08-13 docs(root): fix DXF/brownout/challenge-flow claims, link BOMs, add build-status note
2026-08-13 docs(strategy): correct wire-token statements and ToF/IMU placeholder status
2026-08-13 docs: remove all invented mass/power/torque estimates; replace with TBD measurement framework
2026-08-13 docs(wiring): mark LM317 as dropped, single-pack two-rail buck is current
2026-08-13 docs(strategy): add code-grounded software architecture deep-dive
2026-08-13 v0.6: clean overclaiming, add diagrams, CI, checklist
    - Remove 'authoritative' DXF claims, soften rule-compliance language
    - Mark all placeholders honestly (DXF, photos, STL, .lbrn)
    - Add 5 Mermaid diagrams (system_architecture, state_machine, challenge_flow, wiring_overview, obstacle_strategy)
    - Add CI link-check workflow
    - Add competition day checklist
    - Update diagrams README to reflect committed Mermaid files
    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
2026-08-15 Update README
    Clarified the note about the DXF file and its current state.
2026-08-15 feat: add woodenPlate design file with LightBurn project settings
    [piCamBracket_v1.3.stl]
2026-08-15 Update DXF notes
    Removed placeholder note about chassis reproducibility.
